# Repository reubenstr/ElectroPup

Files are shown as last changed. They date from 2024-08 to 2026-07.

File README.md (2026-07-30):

# ElectroPup

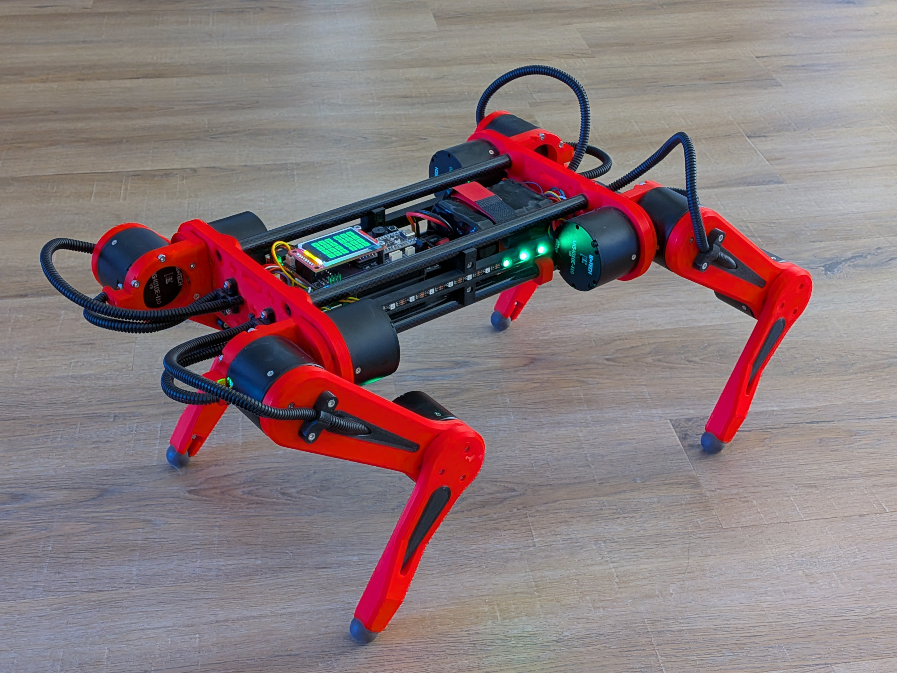
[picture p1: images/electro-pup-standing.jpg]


ElectroPup is a DIY 3D-printed quadruped robot using 'low cost' BLDC motors.

[Video of kinematic poses](https://youtu.be/AJn_wCcWlwo)

[Video of walking, turning, strafing](https://youtu.be/YjTVNw8BXlM)

## Basic Specifications

- RPi 5
- 12x BLDC motors
- Auxiliary board w/LCD display
- 9-axis accelerometer/gyro sensor
- 6s Li-Ion battery, ~72wH
- 4.5kg

ElectroPup's control system is coded in Python. For a ROS2 based quadruped, see my previous project [Zuko](https://github.com/reubenstr/zuko).

# Docs

See the docs directory for a setup guide, bill of materials (BOM), 3D printed parts info, and miscellaneous design notes.

# UI

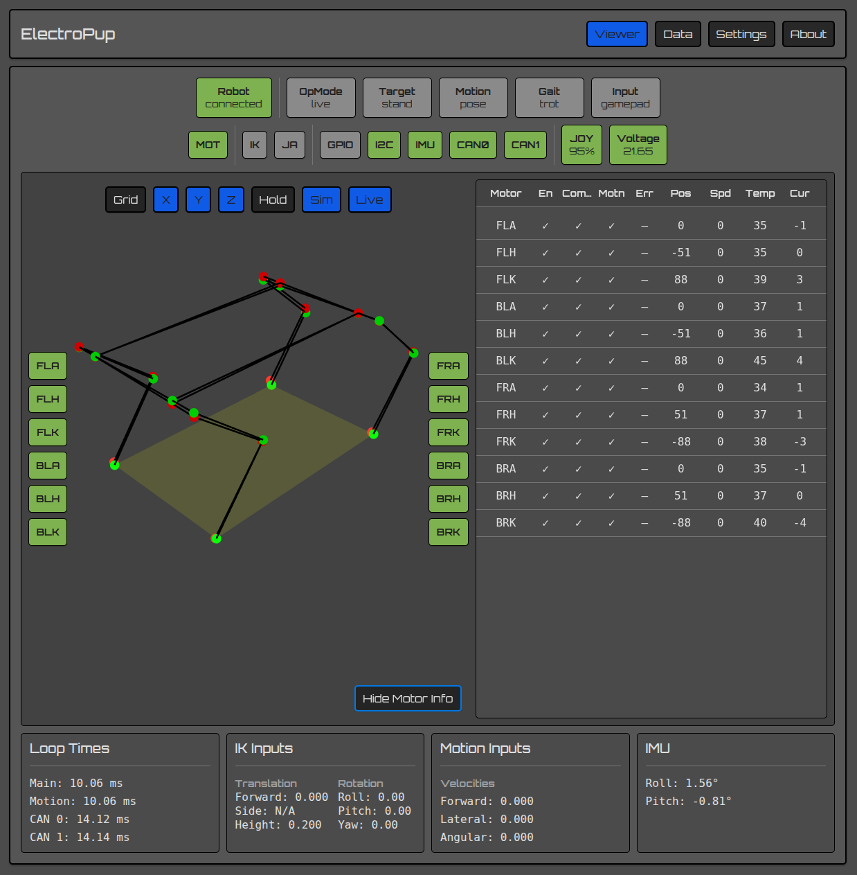
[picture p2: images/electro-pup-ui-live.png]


The UI shows the status of the entire system: quadruped joint positions, subsystem status, motor information, inputs, sensors, loop times, etc. The above image shows the simulated quadruped overlapped with real quadruped (based on motor feedback).

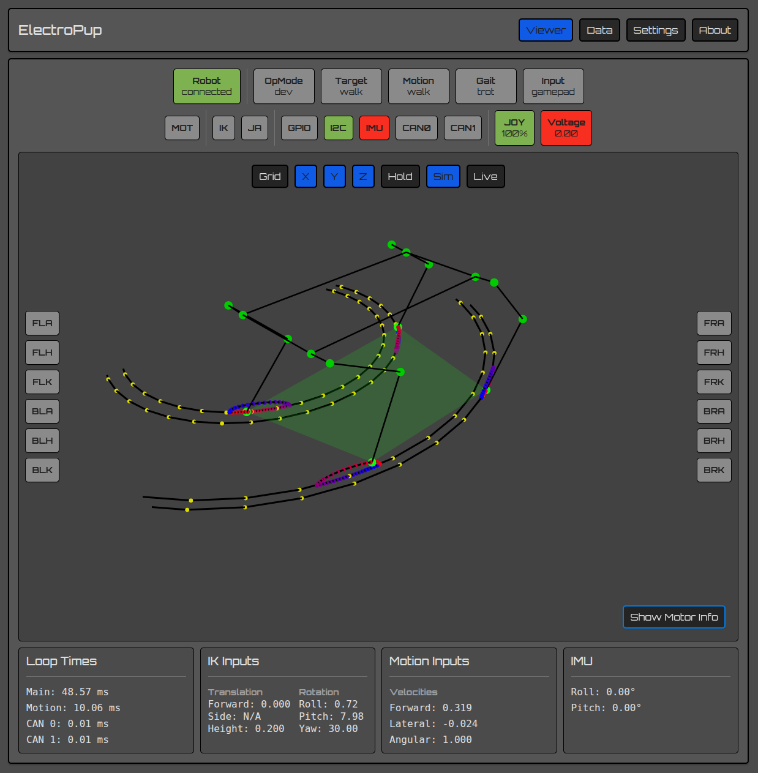
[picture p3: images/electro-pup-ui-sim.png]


The above image shows a virtual circle the feet follow to walk in a circle and the bezier curves used for moving the feet up and down.

The UI is built from the React Native Framework using Expo and runs on web. The app will run on Android without the plot. The entire system runs in dev mode so you can run the simulation and UI from a development PC without physical hardware.

# Kinematics

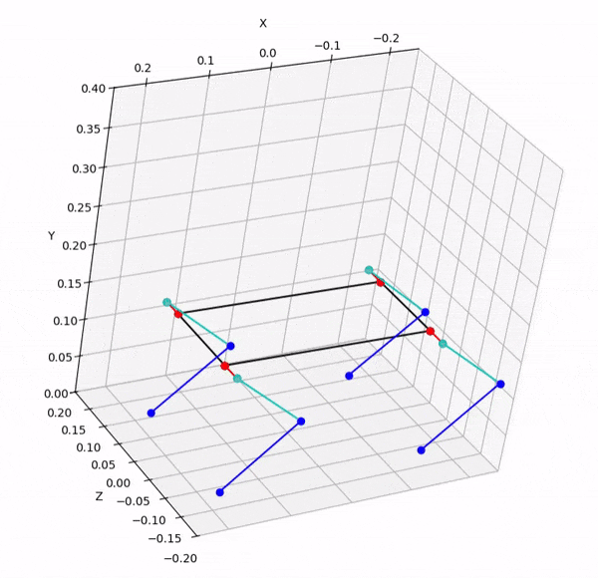
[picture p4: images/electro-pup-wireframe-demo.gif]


Inverse kinematics, leg position, and gamepad inputs are verified using the UI.

### Trajectories

Bezier curves, sin arcs, and curvature projection are used to generate trajectories. The plots below are examples of control points configurations. 

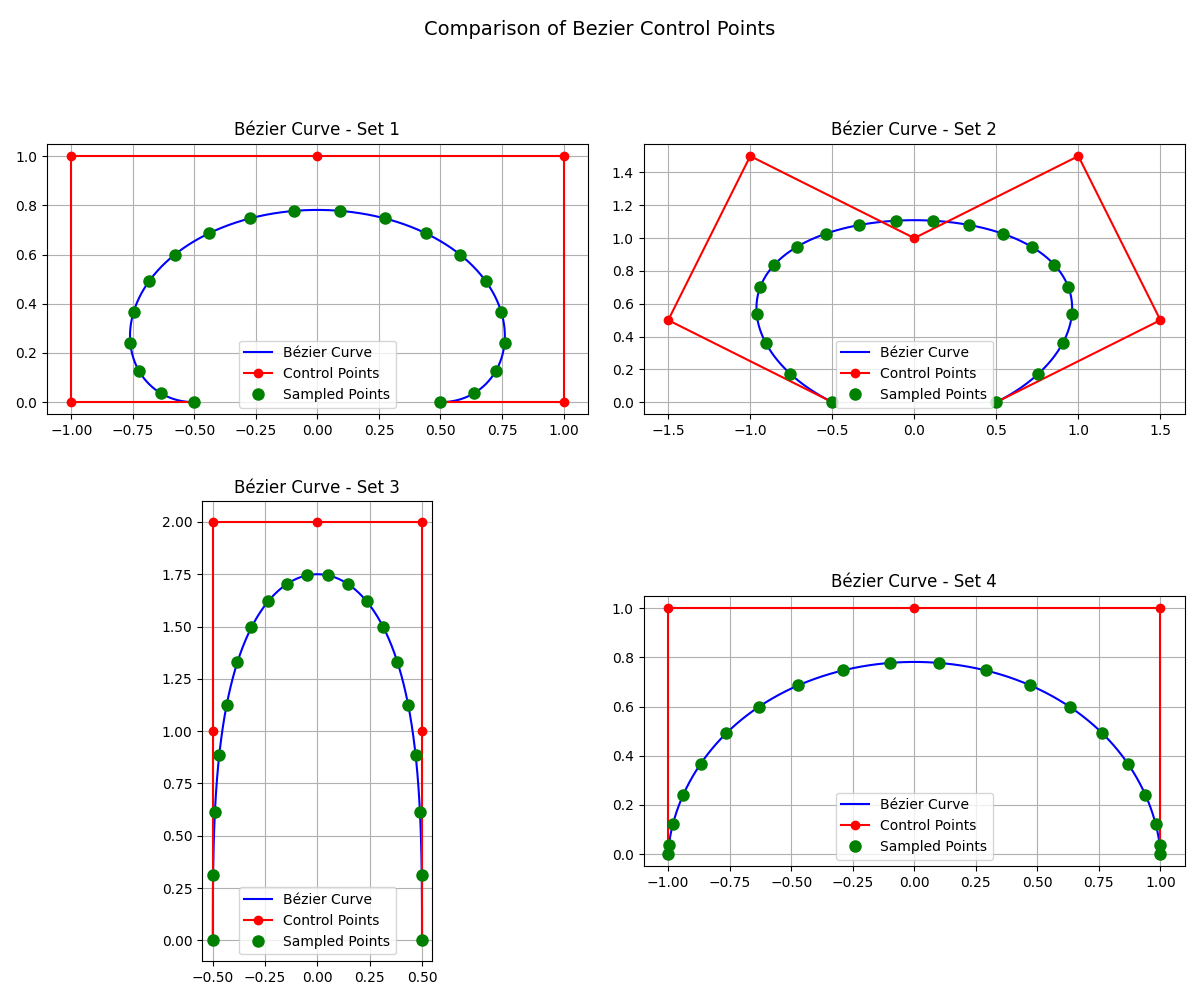
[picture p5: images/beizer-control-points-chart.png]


The output of `./src/plot/bezier_curve_plot.py`

Rotation is achieved by projecting a linear trajectory onto a curve. The plots are of example projection calculations.

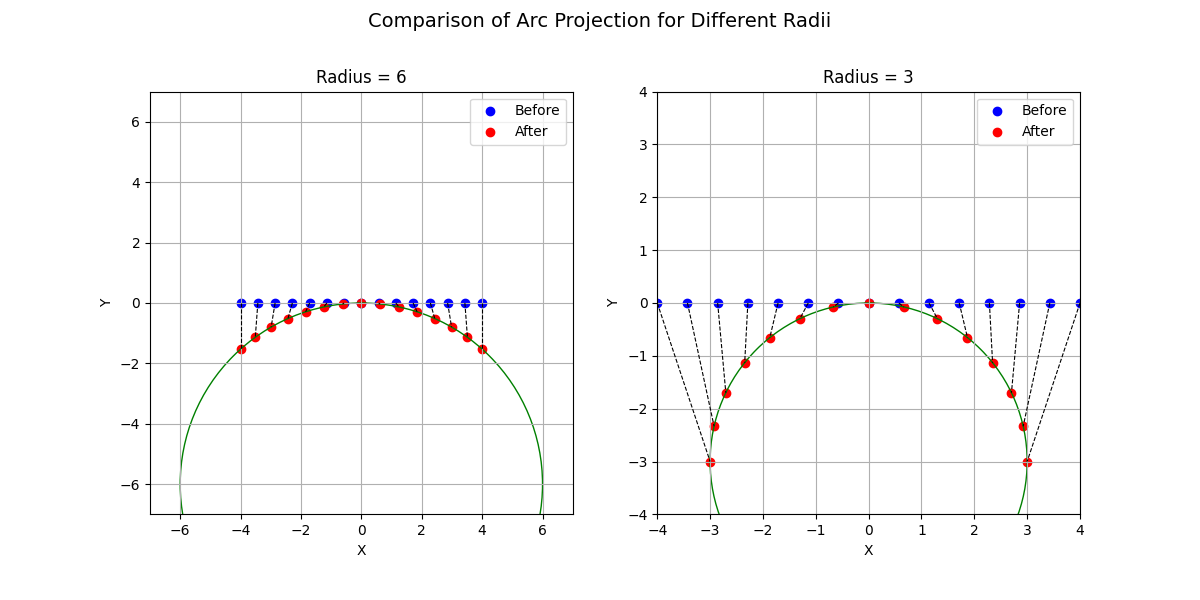
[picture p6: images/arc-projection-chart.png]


The output of `./src/plot/projection_plot.py`

# Simulation

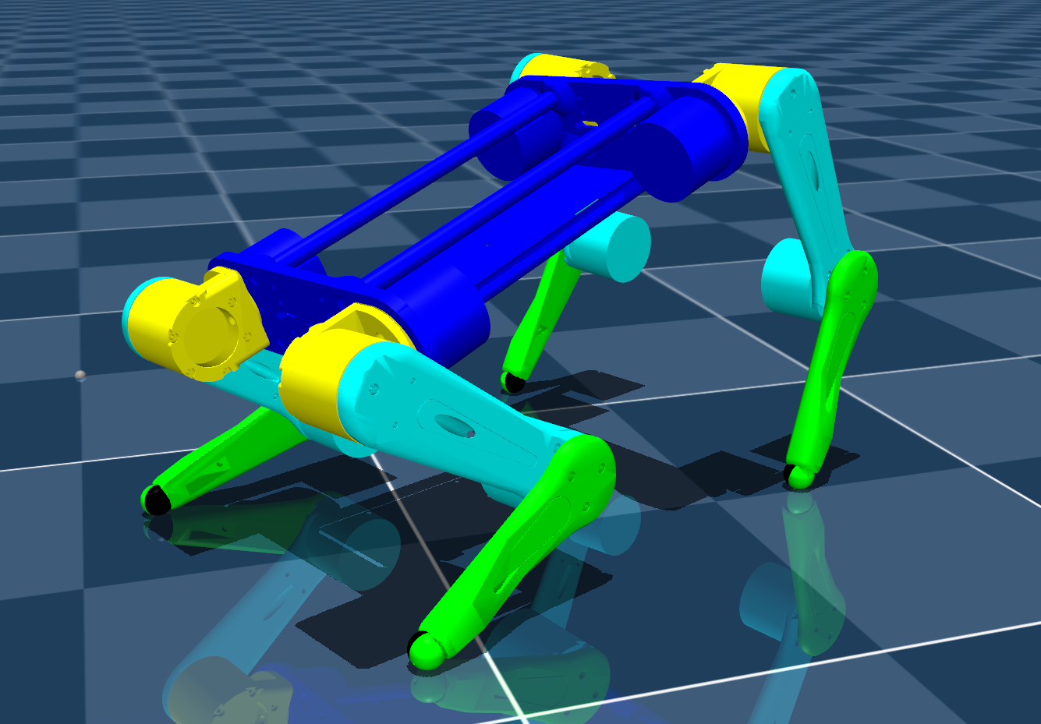
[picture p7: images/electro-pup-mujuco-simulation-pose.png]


Simulation is performed in [MuJoCo](https://mujoco.org/) and can be started by running `./src/sim.sh`. Currently, input controlls are only provided by the gamepad. The `ElectroPup.xml` currently does not have approximate masses or inertial so the simulated quadruped is rather bouncy.

# Electronics

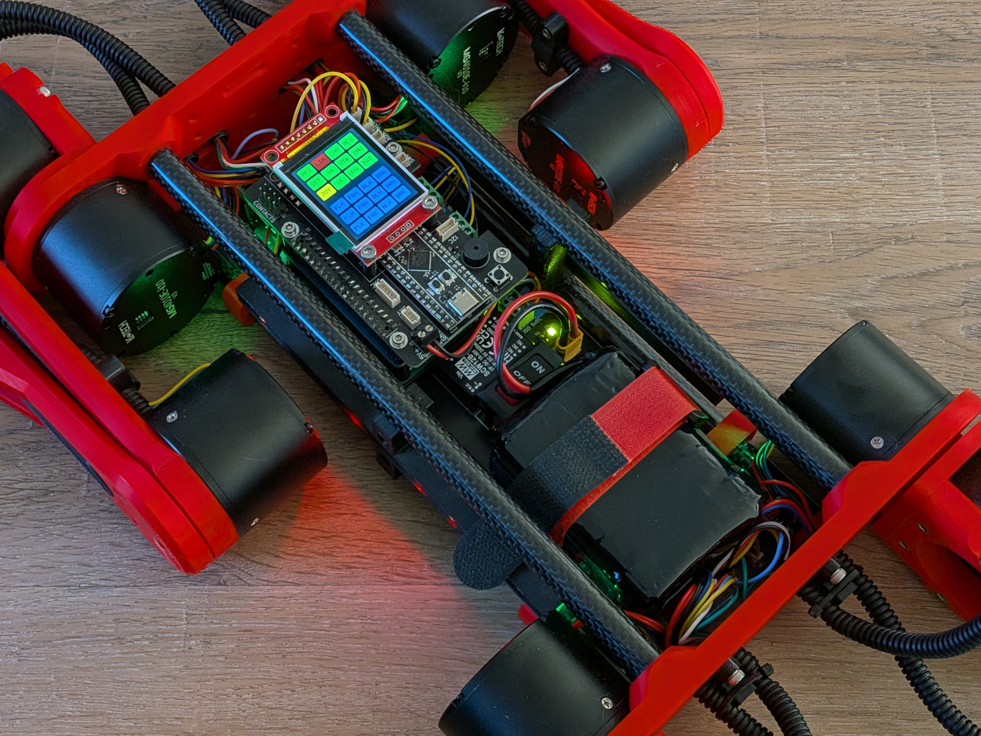
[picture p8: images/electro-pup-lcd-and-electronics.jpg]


## PCBs

PCBs are designed in [KiCad](https://www.kicad.org/) v8 and fabricated by JLCPCB.

### Power Carrier

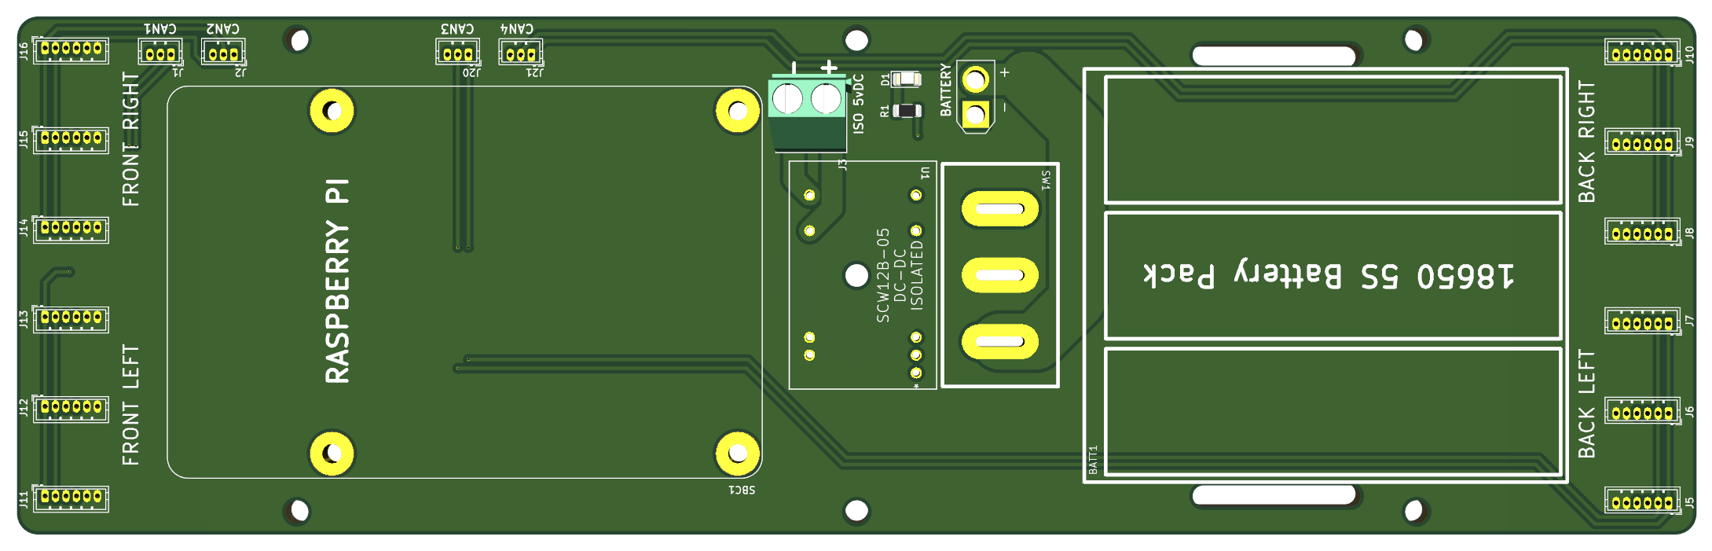
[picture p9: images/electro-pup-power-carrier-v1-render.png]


The Power Carrier PCB provides a main on/off power switch and distributes power to the motor headers. The Power Carrier creates four CAN bus networks one for each leg. Solder jumpers allow merging the front two legs into a single network and the back two legs into another single network.

### Auxiliary Board

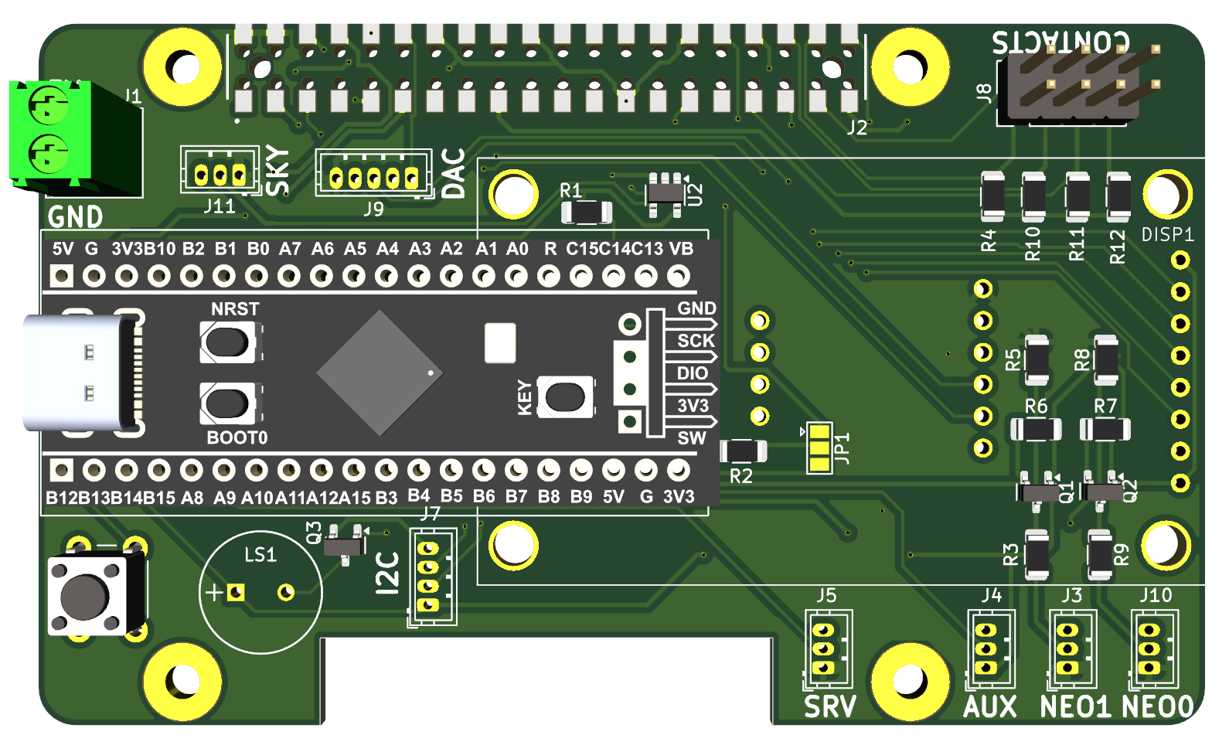
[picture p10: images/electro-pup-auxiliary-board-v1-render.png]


The auxiliary board is optional and not required for the quadruped to operate.

Features:
- Powers RPi via terminal header
- LCD display
- Buzzer (variable pitch)
- NeoPixel strips
- RC Servo channel
- I2C expansion
- Button to control LCD and shutdown Raspberry Pi before power off

Provides direct connection to RPi header for the following breakouts:
- IMU (BNO055 via I2C)
- 4x contact inputs or GPIO
- I2S for sound driver (future barks 🐶)
- SBUS to use RC transmitter if BLE gamepad fails in RF congested areas

# Software Architecture

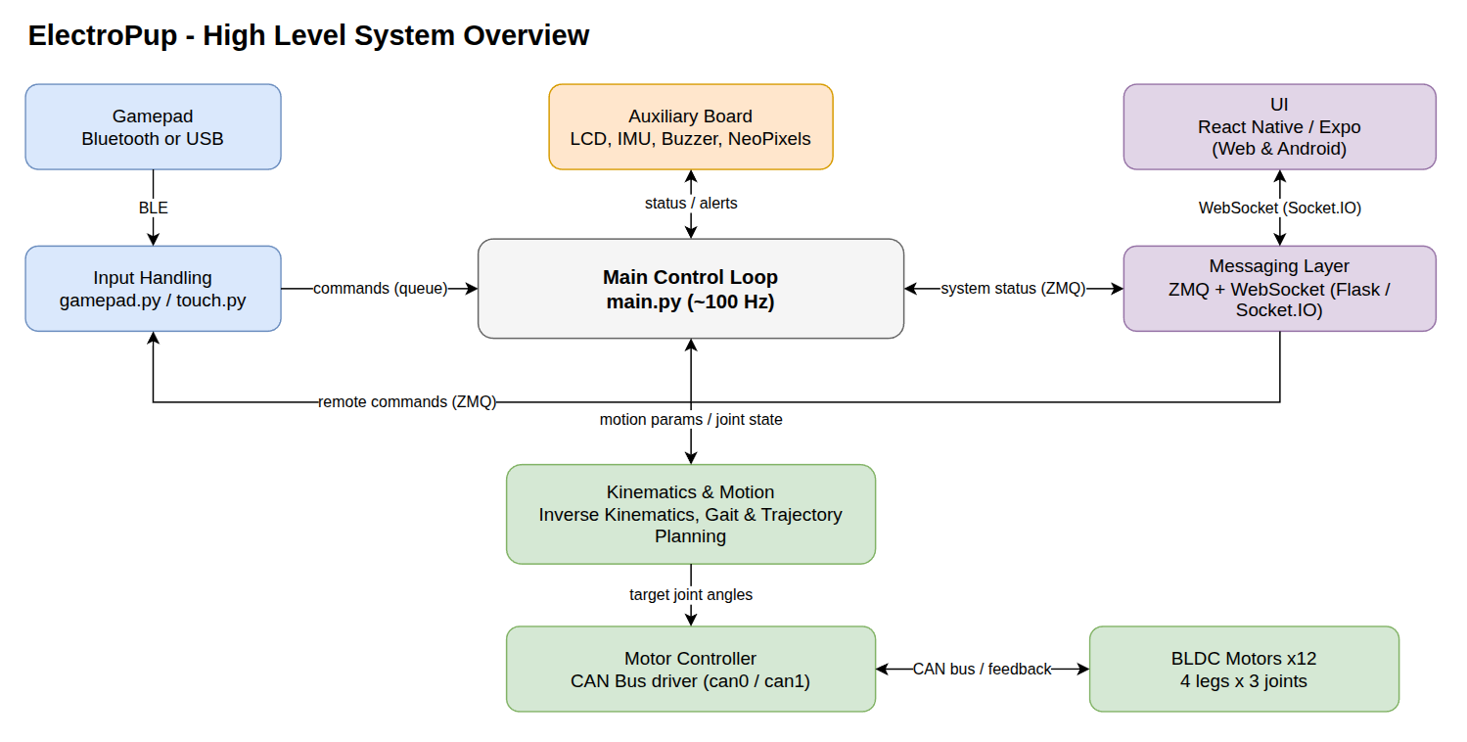
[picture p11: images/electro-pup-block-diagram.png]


Electropup's software architecture was purposely designed to be simple and to bypass the pain points of using ROS2. See my [Zuko]( https://github.com/reubenstr/zuko) robot quadruped for a ROS2 implementation, abiet outdated. A major downside of this single service architecture is needing to sit and stand the quadruped on every software change vs being able to restart individual services quickly without affecting others (i.e. the motors). However, with the simulated quadruped and UI, most development is not performed on a live quadruped.

# Motors

The motors are MG4010E-i10v3 actuators made by LingKong (LKMTECH) and can be purchased from [Aliexpress](https://www.aliexpress.us/item/3256805950420462.html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).

### Specifications
- voltage: 7.4-32V
- communication: CAN 1Mbps
- rated torque: 2.5 N.m
- max torque: 4.5 N.m
- rated current: 3.5 A
- max power: 140 W
- gear ratio: 1:10
- encoders: 18-bit motor, 14-bit reducer
- size: 53mm diameter, 41mm tall
- weight: 238 grams

### MG4010E-i10v3 Pros
- easy to use configuration software over non-proprietary USB to UART hardware
- readable CAN bus communication documentation
- small physical size that works well with the desired frame size of ElectroPup
- non-proprietary power/communications connector (JST-ZH 6-POS)

### MG4010E-i10v3 Cons
- configuration software is Windows only
- closed source firmware
- foreign sourced, complicating the warranty process
- CAN unable to configure all parameters
- UART required to configure error thresholds, motor torque limits (for compliance), etc.
- some motors are more difficult to turn by hand and require slightly more operational current

Future projects will prioritize ODrive compatible drivers.

### Motor Zero Positions

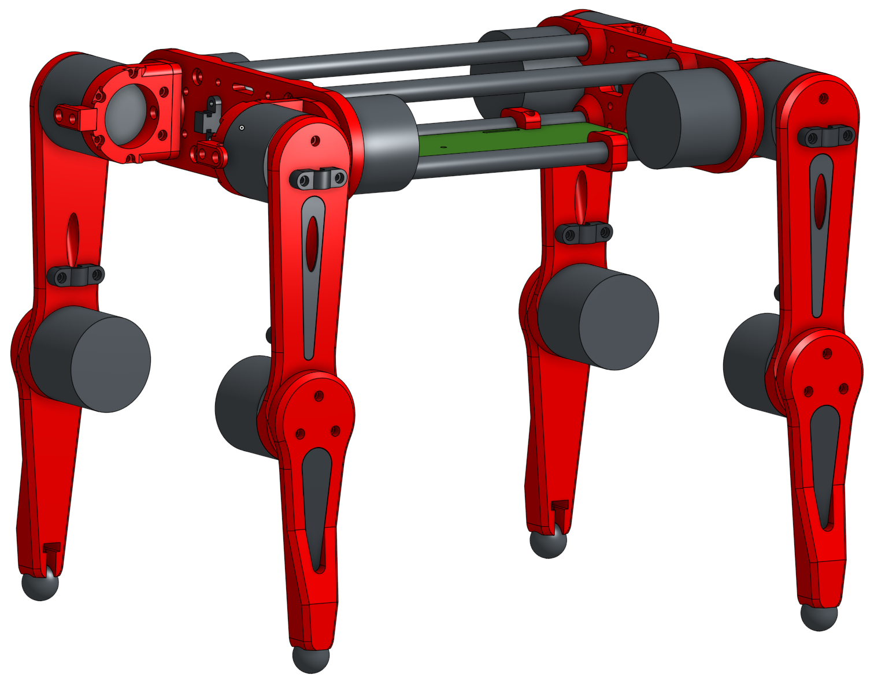
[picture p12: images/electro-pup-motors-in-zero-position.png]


### Motor Tags

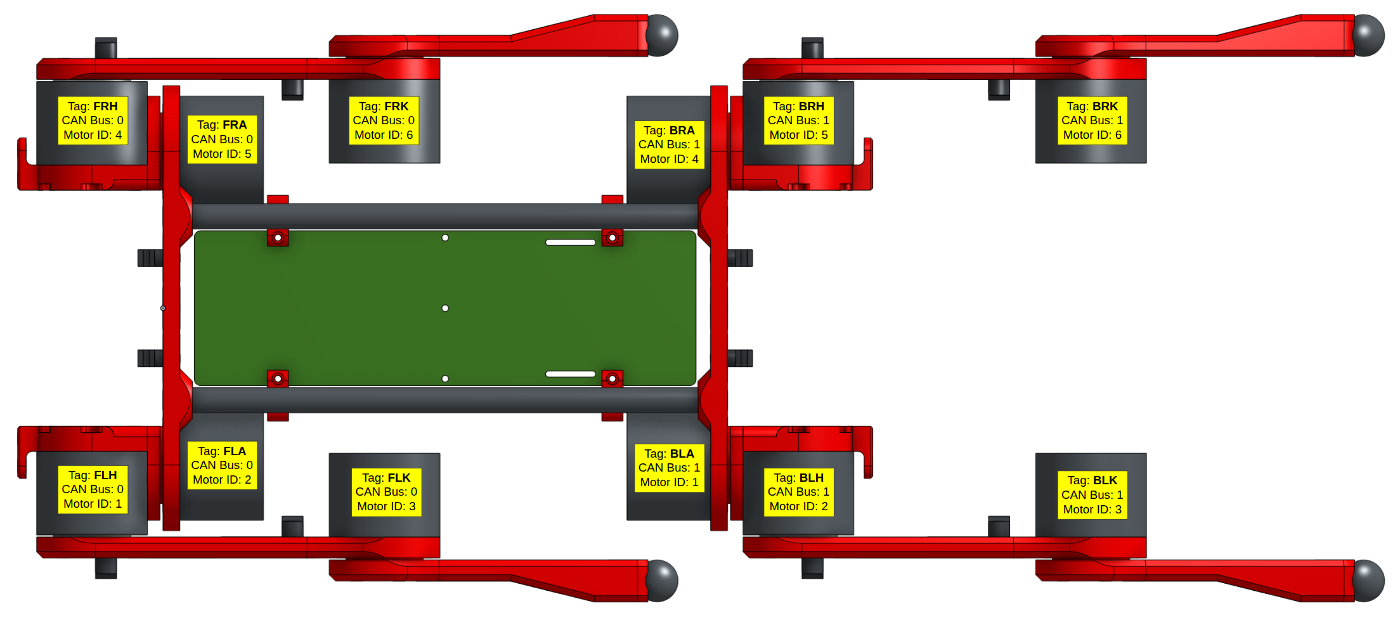
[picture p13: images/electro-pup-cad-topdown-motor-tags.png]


### Motor Calibration

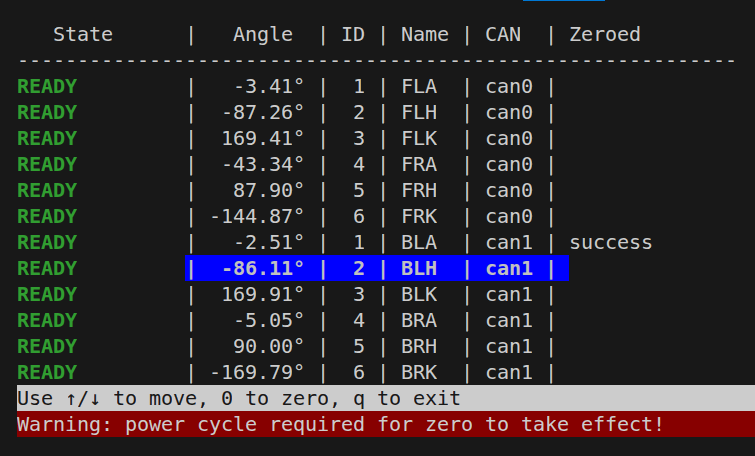
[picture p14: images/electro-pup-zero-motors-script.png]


The zero-motors.py script is a quick way to verify correct motor configuration and to zero the motors.

# CAN Bus

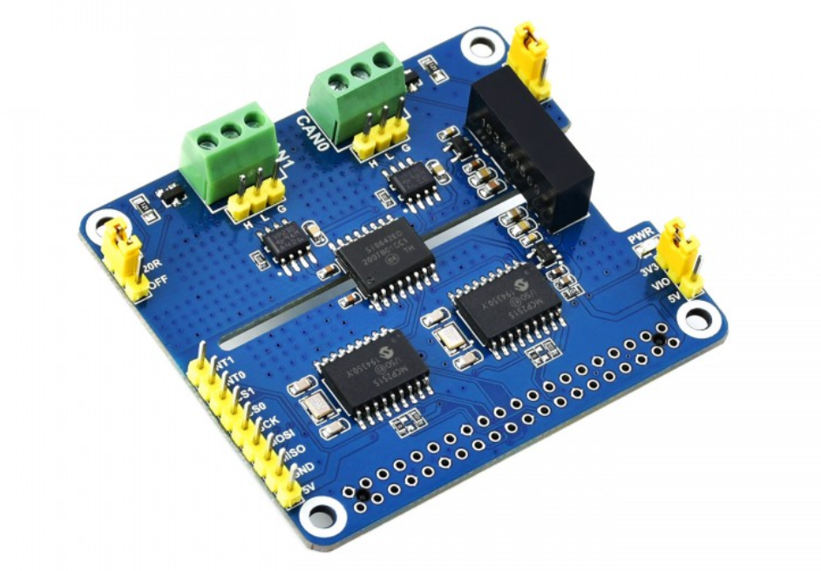
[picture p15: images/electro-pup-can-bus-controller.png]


The CAN bus controller is a [2-Channel Isolated CAN Expansion HAT](https://www.waveshare.com/2-ch-can-hat.htm) from waveshare.

Each CAN controller drives six motors with an average motor update rate of ~70 Hz. This includes fetching encoder position, setting target angle/speed, and getting error states.

# Gamepad

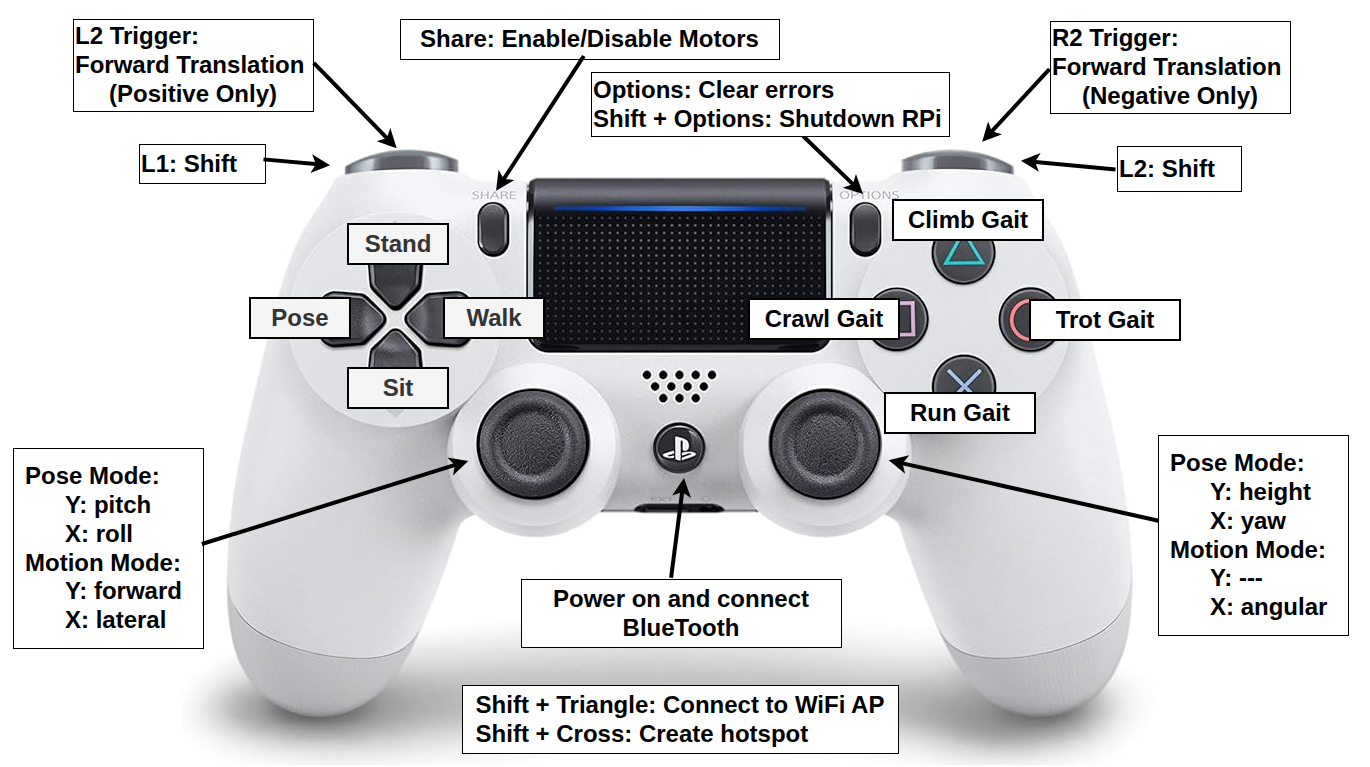
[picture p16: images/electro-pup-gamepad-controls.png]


ElectroPup was coded with a PS4 controller in mind, however xBox, PS5, Logitech gamepads may be used with minor software modifications.

# Environment and IDEs 

There are three hardware/software environments described below.

### PC/Laptop - Plotting, Simulation, and Development

Desktop or laptop computer running Ubuntu Desktop (or your preferred flavor of Linux).

Software: VSCode (with remote SSH and PlatformIO extensions), Drawio, LibreOffice, KiCad, OrcaSlicer, Chrome/Firefox

### Raspberry Pi - Quadruped Hardware Driver

The quadruped compute is a Raspberry Pi 5.

The OS is Raspberry Pi OS Lite (Bookworm 64-bit), which is headless, so all development is performed using remote SSH.

### STM32 - Auxiliary Board

An STM32F401 Black Pill dev kit operates the auxiliary board to display the motor and system status on a LCD display and interface with other peripherals such as the buzzer. 

Uses VSCode with PlatformIO on the PC/Laptop for development.

# Parts

The 3D printed parts are printed using Polymaker PolyMax Tough PLA selected for strength and ease of printing. See these excellent blog posts for more information: [cnckitchen](https://www.cnckitchen.com/blog/the-difference-of-pla-and-pla-tested-feat-polymaker) and [edemargerie](https://www.instructables.com/Comparing-Impact-Resistance-of-21-Filaments-for-3D/).

| Color | Estimated Print Time | Estimated Filament |
| --- | --- | --- |
| main (red) | 25.23 hours | 742 grams |
| accent (black) | 3.58 hours | 92 grams |

### CAD

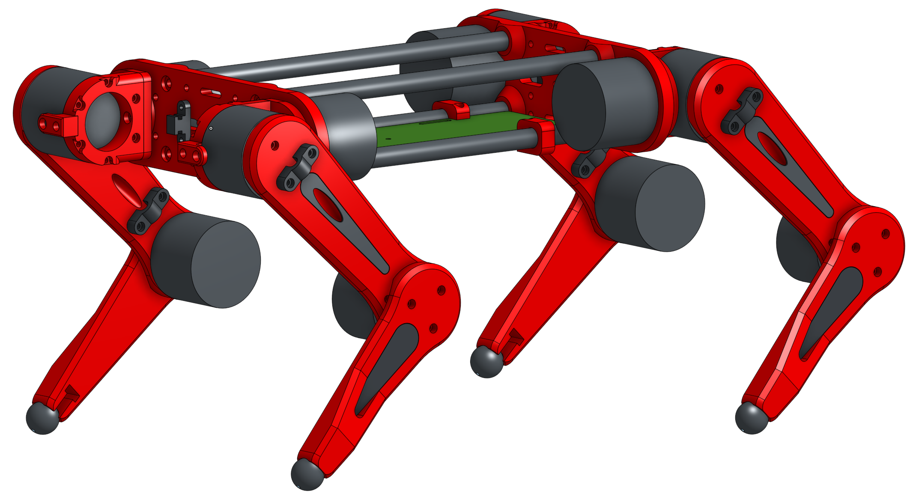
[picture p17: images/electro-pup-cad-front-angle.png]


Parts are modeled using [OnShape](https://www.onshape.com/en/) which provides free web-based full access for non-commercial use. The links below should have export permissions to allow copying the workspace.

- [Assembly](https://cad.onshape.com/documents/b02341d4ebb7f3e9dd488186)
- [Legs](https://cad.onshape.com/documents/6da583196278caf8e90b3122)
- [Body](https://cad.onshape.com/documents/280c24f1b6bdbe8246159786)
- [Hips](https://cad.onshape.com/documents/428031d0c98bf15dcc9f5c8c)
- [Tools](https://cad.onshape.com/documents/3677b35bffbfedb5a3fd2b26)
- [Parts](https://cad.onshape.com/documents/6d4d4e21394ee725ee8ddb38)
- [PCB](https://cad.onshape.com/documents/c8a855826c37bd92b89d9f0e)
- [Neopixels](https://cad.onshape.com/documents/567292ac55c75b2efa25b7d5)

# Battery Pack 

The battery is a custom 6S1P Li-Ion using 18650s with a load balancing BMS. The 18650's are Sanyo branded and rated at 3250mAH each providing an estimated 72Wh.

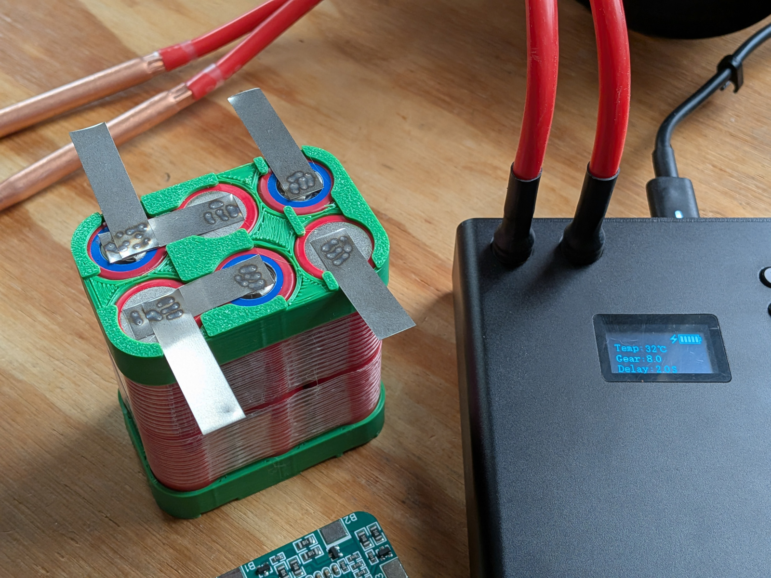
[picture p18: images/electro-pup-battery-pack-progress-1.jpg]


The above image is showing work in progress. The [insulation rings](https://imrbatteries.com/products/18650-terminal-insulators-fish-paper-20pcs-green-round-rings) were forgotten during fabrication and really should be mandatory for any battery build. 

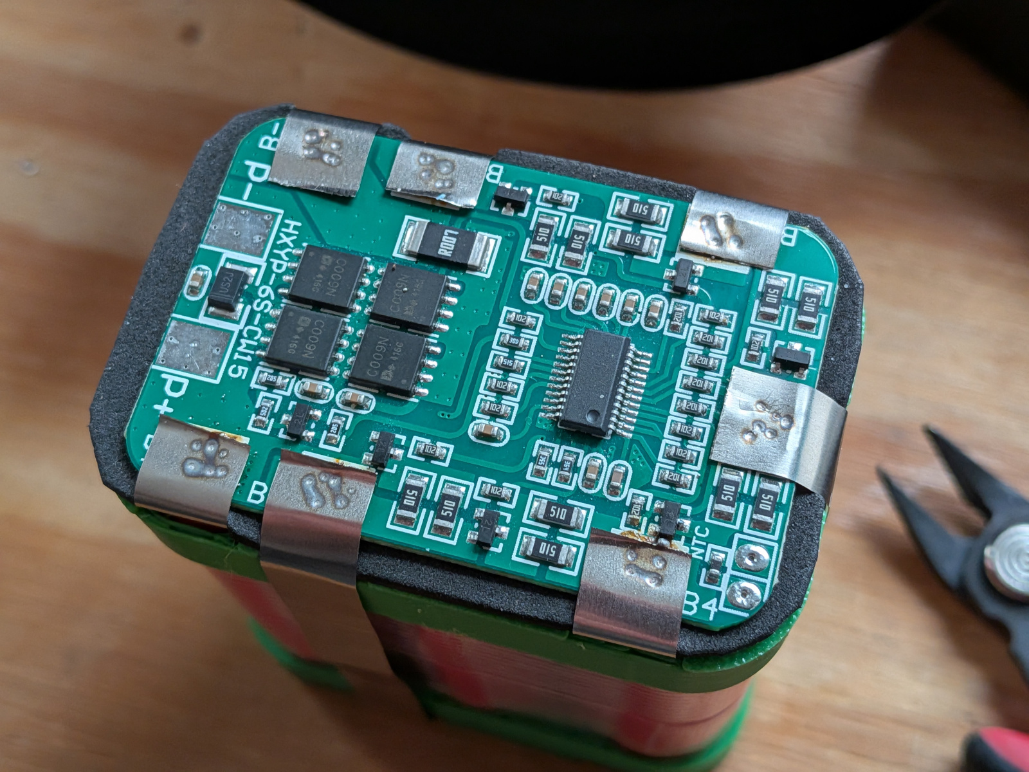
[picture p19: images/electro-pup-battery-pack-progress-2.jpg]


The BMS is a HXYP-6S-CW15.

# Future Improvements  

This is a general improvement list for future updates or revisions. 

- add upside down control (the frame supports walking even after flipped)
- apply IMU for smoother gaits
- add center of mass calculations for smoother gaits
- swap battery and RPi positions for better center of mass
- swap foot lag bolt from SAE to metric
- add curvature to lower leg
- add speaker for barks
- add a tail
- add voltage/current sensor (such as an INA228)
- remove STM32 from aux board and use RPI directly for buzzer, LCD, etc.
- create a [MPC](https://en.wikipedia.org/wiki/Model_predictive_control) controller

# Thoughts

- Due to a lower power consumption than estimated, a larger frame and longer legs can be created. A larger frame would support moving the knee motor to the hip area allowing the lower leg to be belt driven. The reduction of mass of the knee will increase center of mass stability and create smoother gaits.
- Future Auxiliary board revisions will remove the STM32 and either drive the LCD directly from the RPi or remove it completely. The extra complexity outweighs the LCD's usefulness, especially when the GUI provides significantly more data.
- Future power carrier PCB revisions will include a voltage/current sensor such as a INA228 and a fuse.
- The carbon rods twist during the run gait which can be reduced by extending the rods through the hip plates and adding face / butt plates. 
- Future revisions will prioritize adding contact sensors that will allow for better terrain handling and future AI training.
- A full architecture refactor splitting major components into services would have the advantages of individual unit testing and keeping the quadruped standing during development.

# Questions

For any questions please post a new [issue](https://github.com/reubenstr/ElectroPup/issues) on the repo's GitHub page.

# Credits

Inverse kinematics and leg points for plotting were sourced from mike4192: [https://github.com/mike4192/](https://github.com/mike4192/).

Using carbon fiber tube as frame supports inspired from [Open Dog 3](https://www.youtube.com/watch?v=ts2l_Em7fpI&list=PLpwJoq86vov8uTgd8_WNgBHFpDYemO-OJ&index=3) by James Bruton.

There are many excellent open source quadruped robot projects at various sizes, costs, and complexity. Below are projects and code examples worth checking out.

- https://github.com/mit-biomimetics/Cheetah-Software
- https://github.com/mike4192/spotMicro
- https://github.com/mike4192/spot_micro_kinematics_python
- https://spotmicroai.readthedocs.io/en/latest/
- https://github.com/adham-elarabawy/open-quadruped
- https://www.youtube.com/jamesbruton
- https://github.com/chvmp/champ
- https://grabcad.com/library/diy-quadruped-robot-1
- https://github.com/Jerome-Graves/yertle
- https://www.youtube.com/@Jorgefer88
- https://www.youtube.com/watch?v=oYnsCE2H6ss
- https://github.com/JackDemeter/quadruped-robot
- https://github.com/reubenstr/zuko

# AI Disclosure

Project concept, aesthetic, engineering design, and original code base were conceived and executed by the author.

Portions of this codebase were reviewed, revised, and written with the assistance of Claude Code (Anthropic).

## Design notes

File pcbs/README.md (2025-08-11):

# PCBs

PCBs are designed in [KiCad](https://www.kicad.org/) (v8)

Custom libraries used for these projects may be found on my github repo: [https://github.com/reubenstr/kicad-libraries](https://github.com/reubenstr/kicad-libraries)

See the README.md in each project for next revision error fixes.

## Auxiliary Board

This board uses a STM32 co-processor to add the following functionality to the system:

- LCD display for error indication and status such as battery levels
- 1x buzzer
- 2x Neopixel strips
- 1x RC servo
- 1x button

This board also provides the following Raspberry Pi connection breakouts:
- BNO055 IMU
- SBUS FrSKY RC receiver input
- I2S header
- 4x contact switches (or aux GPIO)

## Power Carrier

This board provides the following functionality:
- Power distribution for the actuators
- CAN bus networks for the actuators
- Isolated DC-DC for the Raspberry Pi
- Main power On/Off switch
- Battery holder and power connection

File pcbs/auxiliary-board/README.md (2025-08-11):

# TODO / Fixes

- Add version number to silkscreen
- Change terminal footprint to match the now used terminal: WM7877-ND 
- Add a switch for WiFi AP/Client switching
- LCD holes are not aligned and are off slightly
- Change 40 pin header from SMD to through-hold
- Consider adding a second tactile button

# General Thoughts

- Removing the Black Pill in favor of using a STM32 directly on the board will save space and allow the addition of more breakouts such as buttons.

- Removing the LCD PCB and directly connecting a LCD to the board will reduce the height of the board that will decrease the chance of screen damage when the quadruped rolls over.

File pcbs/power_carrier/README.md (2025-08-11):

# TODO / Fixes

- Add voltage/current sensor such as a INA228
- Add revision number to silkscreen
- Optional: Add motor tags (ex, FLA, FLH, FLK) to silkscreen
- Move 5vDC terminal away from RPi as this blocks the power switch if a RPi 5 is used.
- Some of the PCB may be removed to save weight, perhaps under the battery.

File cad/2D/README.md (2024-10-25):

# 2D CAD

electropup.dwg contains the 2D CAD drawing of the quadruped.

2D CAD was used as a quick method to layout major components and determine part sizes prior to generating parts in 3D CAD.

The 2D CAD drawing has not been updated to reflect the final 3D version.

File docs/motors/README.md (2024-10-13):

# Actuators

Model: MG4010E-i10v3

Purchased from the Chinese company LingKong (Shanghai Lingkong Technology Co., Ltd.) also branded as LKMTECH 

LingKong products: http://en.lkmotor.cn/Product.aspx

Aliexpress: https://www.aliexpress.us/item/3256805950420462.html

As of 09/2024 LingKong has not released the CAD model of the MG4010E-i10v3

# Misc.

There is ESP32 project to communicate using the common MCP2515 SPI CAN controller: https://github.com/project-sternbergia/lkm_m5/tree/main

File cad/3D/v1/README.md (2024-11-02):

# 3D CAD : V1

Version 1 parts as STLs for quick reference.

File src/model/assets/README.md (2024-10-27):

# Assets

For model infomation and links see the cad/3D/README.md doc.

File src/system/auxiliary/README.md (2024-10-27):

# Auxiliary

Auxiliary is a set of optional functionality that sends system status data
to the auxiliary Raspberry Pi hat with a display, neopixels, and misc hardware.

## Heartbeat

The auxilary board expects a heartbeat signal (on GPIO17) from the Raspberry Pi as an indication
if the Raspberry Pi has booted and is operational.

Execute the install_heartbeat.sh on the Raspberry Pi to install and start the heartbeat service.

Check the service status:
>sudo systemctl status heartbeat.service 

Stop the service:
>sudo systemctl stop heartbeat.service 

Start the service:

>sudo systemctl start heartbeat.service

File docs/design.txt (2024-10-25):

###############################################################################
# Design
###############################################################################

Notes taken during the design process.

###############################################################################
# MG4010E Motors
###############################################################################

Measured motor bolt MAX depths:
Front frame: M2.5 x 8.5mm, recommended max: 8mm
Front motor wheel: M3 x 6mm, recommended max: 5.5mm
Front motor wheel pin: M3 x 3mm, recommended max 2.5mm

###############################################################################
# MIT Mini Cheetah
###############################################################################

The MIT Mini Cheetah was source of inspiration and it's dimensions are recorded as a sanity check to help ElectroPup's frame stays within common proportions.

Units: mm
Frame width (side to side): 194
Frame length (front hip plate to back hip plate): 304
Frame thickness (top to bottom): 94

Hip width (actuator center ot actuator center): 236.5
Hip length (actuator center to actuator center): 392

Hip center motor to upper leg (actuator center to actuator center): est. 82

Foot width (ball to ball): 256
Foot length (ball to ball): 392

Upper leg length: 212.4
Lower leg length: 205

###############################################################################
# Other Motors and Interfaces
###############################################################################

https://github.com/open-dynamic-robot-initiative/blmc_drivers?tab=readme-ov-file
https://open-dynamic-robot-initiative.github.io/robot_interfaces/doc/real_time.html

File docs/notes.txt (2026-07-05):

###############################################################################
# Notes
###############################################################################

Notes taken during design, testing, and assembly.

###############################################################################
# Power
###############################################################################

Fully loaded:
    Abduction at zero degrees, legs at 45 degrees
    Suspended (motors disabled): 1.08A @ 20vDC = 21.6 watts
    Standing (motors enabled): 1.79A @ 20vDC = 33.8 watts

Battery:
    6x 18650 in series, 24v nominal
    At 3300mAh per cell: 12.21Wh x 6 == 73.26Wh

###############################################################################
# Body
###############################################################################

Carbon fiber tube: 12mm OD, 10mm ID, 254mm length
In retrospect the frame probably could of been shorted by 4mm to require 250mm 
tubes as this is a more common length. However, only a few listings (aliexpress only)
have been found at the required dimensions at 250mm length.

To use a 250mm length either the Power Carrier PCB will need to be shortend (by 2 to 4mm),
or a slot can be added to the hip plate to allow the PCB to slip in the needed ~1mm per end.

The carbon fiber rods have PLA inserts on both ends which in turn holds a M5 brass insert.
The PLA inserts attach to the ends of the rod using superglue. 
About five minutes after the superglue is applied the threaded inserts can be applied to the PLA insert. 
(Do not wait for the glue to cure.)
Superglue will ooze out from the PLA insert which will allow the PLA insert to better form to the rod.

When attaching the carbon fiber rods to the hip plate, add the PCB clips to the lower rods first, then attach the rods loosely.
Place the body on a flat surface and while holding the hip plates down cycle through each rod tightening the rod a little bit each cycle.

###############################################################################
# Motor and Leg Hardware
###############################################################################

Hip:
    motor front: 6x M2.5x12mm
    motor wheel: 2x M3x14mm
    motor wheel: 1x M3x25mm

Upper Leg:    
    motor back: 6x M3x18mm
    motor wheel: 1x M3x12mm
    motor wheel: 2x M3x20mm  
    motor wheel pin: 3x M3 x 8mm
    wireclip upper side: M3x8mm (M3x10mm OK)
    wireclip lower side: M3x8mm (M3x10mm OK)

Lower Leg:    
    motor front: 6  
    motor wheel: 3x M3x20mm
    motor wheel pin: 3x M3 x 8mm

###############################################################################
# Motors
###############################################################################

After the all the motors are physically attached each motor will need to be configured 
prior to connecting the final wiring.
(See docs for motor ID and parameter setup)

###############################################################################
# Motor Cables 
###############################################################################

Motor cables use 6 position JST-ZH headers on each end and have the following lengths (housing to housing):
4x each: 60mm, 235mm, 465mm

Motor cables are contained in 7mm OD splitloom tubing and have the following lengths:
4x each: 155mm, 465mm

The short length cables are made from the cable that was provided with the motor.
The longer length cable is made from 26AWG silicon wire.

The crimps on the second housing for the two longer cables should be placed into the housing until after the cable is routed through the wire clip and leg.

###############################################################################
# CAN Bus Communication
###############################################################################

Timing sample of processing 6 motors on a single CAN bus:
    Performs: 
        self._worker_set_all_targets()                                
        self._worker_get_all_angles()                                        
        self._worker_get_all_status()                
        self._worker_check_all_angle_limits() 
    Capture (milliseconds):
        [Motors] processing time: 12.37
        [Motors] processing time: 16.80
        [Motors] processing time: 12.23
        [Motors] processing time: 17.36
        [Motors] processing time: 12.58
        [Motors] processing time: 12.00
        [Motors] processing time: 16.46
        [Motors] processing time: 11.73
        [Motors] processing time: 15.99
        [Motors] processing time: 12.25
        [Motors] processing time: 16.09
        [Motors] processing time: 12.59
        [Motors] processing time: 15.77
        [Motors] processing time: 12.09
        [Motors] processing time: 16.13
        [Motors] processing time: 12.58
        [Motors] processing time: 15.24
        [Motors] processing time: 12.61
        [Motors] processing time: 16.75

###############################################################################
# Tools
###############################################################################

Make gifs:
https://ezgif.com/

Make LCD splashscreen:
https://github.com/riuson/lcd-image-converter

Better top:
sudo apt install htop

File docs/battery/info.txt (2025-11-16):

6x 18650 in series forr 24v nominal.
At 3300mAh per cell: 12.21Wh x 6 == 73.26Wh

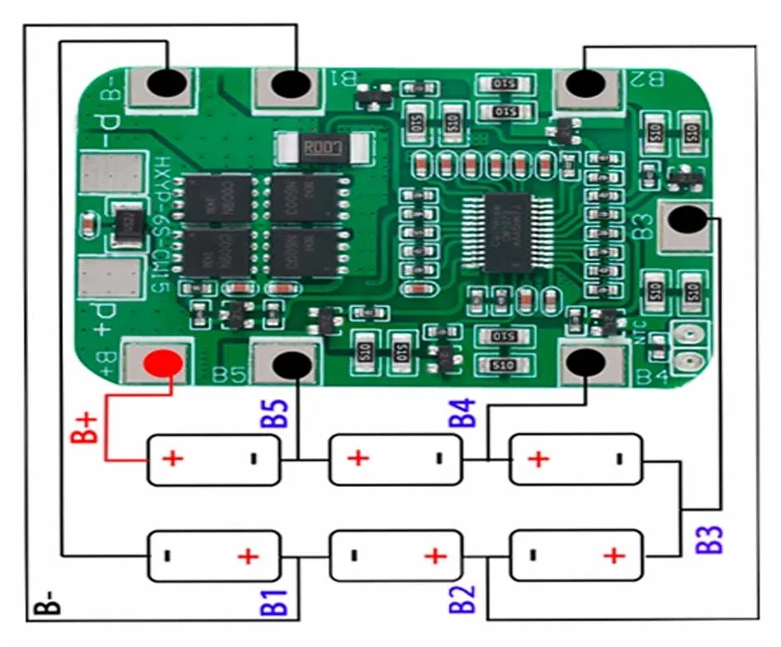
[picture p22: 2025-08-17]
docs/battery/6s-18650-lipo-general-connections.png

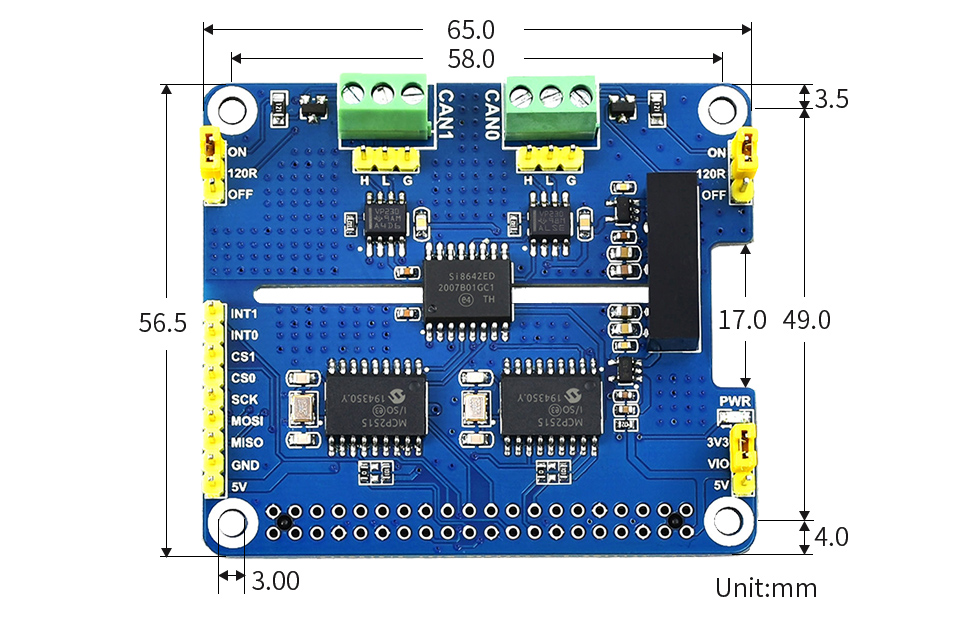
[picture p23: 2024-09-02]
docs/can/2-CH-CAN-HAT-17_960.jpg

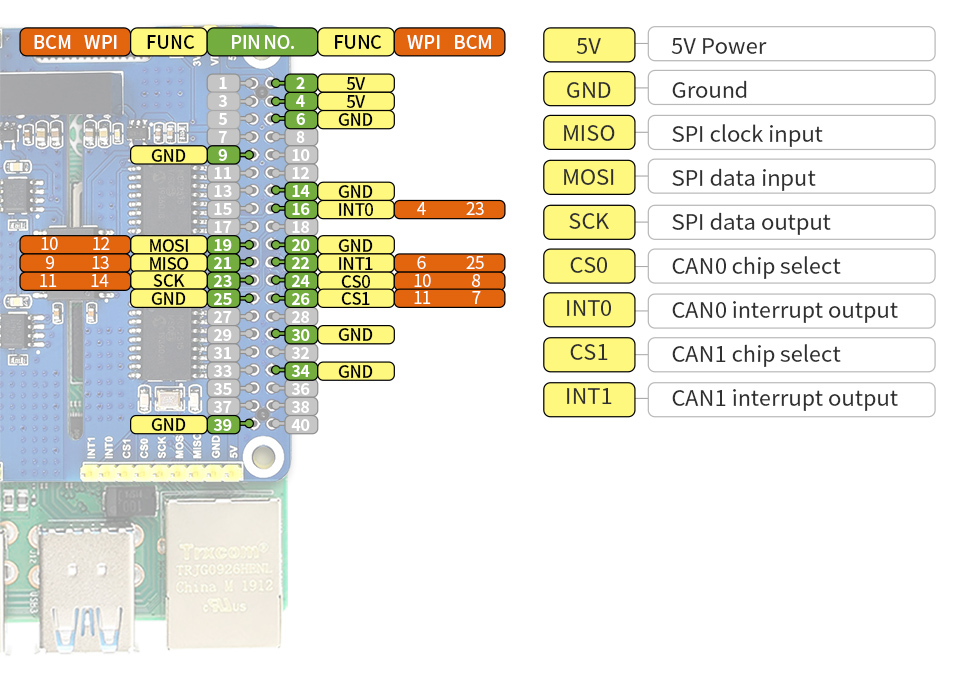
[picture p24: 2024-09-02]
docs/can/2-CH-CAN-HAT-15_960.jpg

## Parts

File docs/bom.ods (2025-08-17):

Bill of Materials
Costs are for estimate purposes only and may not include bulk orders, taxes, tariffs, or shipping.
You will always need more parts than the final quantity due to losses and failures.
Links are provided as reference only, carefully review before making purchases.
Hardware | Qty | Est. Cost | SubTotal | Link 1 | Link 2 | Notes
M2.5x12mm socket head bolt | 24 | 0.05 | 1.2 | mcmaster (https://www.mcmaster.com/91292A115/)
M2.5x14mm socket head bolt | 24 | 0.05 | 1.2 | mcmaster (https://www.mcmaster.com/91292A017/)
M2.5x40mm socket head bolt | 4 | 0.261 | 1.044 | mcmaster (https://www.mcmaster.com/91292A837/)
M3x8mm socket head bolt | 32 | 0.05 | 1.6 | mcmaster (https://www.mcmaster.com/91292A112/)
M3x12mm socket head bolt | 4 | 0.05 | 0.2 | mcmaster (https://www.mcmaster.com/91292A112/)
M3x14mm socket head bolt | 8 | 0.05 | 0.4 | mcmaster (https://www.mcmaster.com/91292A027/)
M3x16mm socket head bolt | 4 | 0.05 | 0.2 | mcmaster (https://www.mcmaster.com/91292A027/)
M3x18mm socket head bolt | 24 | 0.05 | 1.2 | mcmaster (https://www.mcmaster.com/91292A029/)
M3x20mm socket head bolt | 20 | 0.05 | 1 | mcmaster (https://www.mcmaster.com/91292A123/)
M3x25mm socket head bolt | 4 | 0.05 | 0.2 | mcmaster (https://www.mcmaster.com/91292A027/)
M5x16mm low-profile bolt | 8 | 0.25 | 2 | amazon (https://www.amazon.com/M5-Countersunk-Socket-Screws-Furniture/dp/B0CKW3791R) | aliexpress (https://www.aliexpress.us/item/3256806833766304.html)
M2.5 nylon lock nut | 4 | 0.1 | 0.4 |  | aliexpress (https://www.aliexpress.us/item/2251832612458814.html)
M3x4mm 4.5mm diameter brass insert | 28 | 0.05 | 1.4 |  | aliexpress (https://www.aliexpress.us/item/3256805034317562.html)
M5x10mm 7mm diameter Brass Insert | 8 | 0.25 | 2 |  | aliexpress (https://www.aliexpress.us/item/3256803396040989.html)
M3x8mm Pin (non-threaded) | 36 | 0.12 | 4.32 |  | aliexpress (https://www.aliexpress.us/item/3256807033465642.html)
1/4-in x 1-in Zinc-Plated Hex-Head Lag Screws | 4 | 0.23 | 0.92 |  | lowes (https://www.lowes.com/pd/Hillman-1-4-in-x-1-in-Silver-Zinc-Plated-Hex-Head-Interior-Lag-Screw/3036823) | Used to attach foot beads to lower leg. M6 25mm is metric equivalent, lower leg model will need tweaked
Frame
Polymaker PolyMax Tough PLA Red - 1.75mm – 750g | 2 | 29.99 | 59.98 | amazon (https://www.amazon.com/dp/B09KLFPZFJ)
20mm silicon bead | 4 | 1.38 | 5.52 | aliexpress (https://www.aliexpress.us/item/3256805271172037.html) |  | Feet
Carbon fiber tube 12mm ID x 10mm ID x 254mm | 4 | 5 | 20 | amazon (https://www.amazon.com/dp/B0D546MSBL) |  | If purchasing 250mm lengths, the hip plate needs a slight modification for fit
Electromechanical
MG4010E-i10v3 actuator (CAN version) | 12 | 134 | 1608 | aliexpress (https://www.aliexpress.us/item/3256805950420462.html) |  | Purchase as needed to avoid expensive tariffs! (sets of three)
Electronics
PCB: Power Carrier | 1 | 15 | 15 |  |  | Split cost after shipping from JLCPCB
PCB: Auxiliary Board | 1 | 15 | 15 |  |  | Split cost after shipping from JLCPCB
Raspberry Pi 4 | 1 | 55 | 55 | digikey (https://www.digikey.com/en/products/detail/raspberry-pi/SC0194-9/10258781)
Micro SD card | 1 | 10 | 10
Waveshare 2-Ch CAN Bus HAT | 1 | 25.99 | 25.99 | amazon (http://18650batterystore/) | waveshare (https://www.waveshare.com/2-ch-can-hat.htm)
40 pin header | 1
40 pin header | 1
Gamepad – PS4 Controller | 1 | 30 | 30 |  |  | xBox, PS5, or F710 controllers will work with minor software changes
WS2812b strip – 5mm wide, black PCB, 5V | 1 | 4.96 | 4.96 |  | aliexpress (https://www.aliexpress.us/item/3256806803085615.html) | Non-water proof for easier soldering. Link is for white PCB.
26AWG Silicon wire assorted colors | 1 | 18 | 18 | amazon (http://BNO055/) |  | A assorted box with 6 colors is by far more than enough wiring
Split loom tubing, 7mm OD | 1 | 1.99 | 1.99 |  | aliexpress (https://www.aliexpress.us/item/3256803623149093.html)
STM32 Black Pill dev kit | 1 | 3.07 | 3.07 | amazon (https://www.aliexpress.us/item/3256801269871873.html) | aliexpress (https://www.aliexpress.us/item/3256801269871873.html)
LCD display 128x160 1.8” (HiLetGo) | 1 | 2.45 | 2.45 | amazon (https://www.amazon.com/DIYmalls-Display-Interface-ST7735S-Mega2560/dp/B0BFDQDGSQ) | aliexpress (https://www.aliexpress.us/item/3256806134563059.html)
BNO055 IMU Adafruit Layout | 1 | 29.95 | 29.95 | adafruit (https://www.adafruit.com/product/4646)
2.54mm header low-profile | 1 |  |  |  |  | For LCD. TBD
SWITCH ROCKER SPST 20A 125V | 1 | 1.27 | 1.27 | digikey (https://www.digikey.com/en/products/detail/zf-electronics/CRE22F4DBBNE/446067)
DC DC CONVERTER 5V 12W | 1 | 16.91 | 16.91 | digikey (https://www.digikey.com/en/products/detail/mean-well-usa-inc/SCW12B-05/7706439)
BUZZER MAGNETIC 3V 9MM TH | 1 | 2.04 | 2.04 | https://www.digikey.com/en/products/detail/mallory-sonalert-products-inc/PB-09N23P-03Q/3196328
SWITCH TACTILE SPST-NO 0.05A 24V | 1 | 0.16 | 0.16 | https://www.digikey.com/en/products/detail/te-connectivity-alcoswitch-switches/1825910-6/1632536
IC INVERTER 1CH 1-INP SOT23-5 | 1 | 0.83 | 0.83 | https://www.digikey.com/en/products/detail/texas-instruments/SN74LVC1G14DBVT/1592006
TRANS NPN 40V 0.6A SOT23-3 | 2 | 0.1 | 0.2 | https://www.digikey.com/en/products/detail/onsemi/MMBT2222ALT1G/919593
RES 10K OHM 1% 1/8W 0805 | 12 | 0.02 | 0.24 | https://www.digikey.com/en/products/detail/vishay-dale/CRCW080510K0FKEAC/7928398
RES 1.2K OHM 1% 1/4W 1206 | 1 | 0.1 | 0.1 | https://www.digikey.com/en/products/detail/yageo/RC1206FR-071K2L/728411
RES 500 OHM 1% 1/4W 1206 | 2
LED GREEN CLEAR 1206 SMD | 1 | 0.22 | 0.22 | https://www.digikey.com/en/products/detail/w%C3%BCrth-elektronik/150120GS75000/4489936
TERM BLK 2POS SIDE ENT 3.5MM PCB | 2 | 1.27 | 2.54 | https://www.digikey.com/en/products/detail/molex/0393570002/946543
3-pos JST-ZH header | 5 | 0.161 | 0.805 | https://www.digikey.com/en/products/detail/jst-sales-america-inc/B3B-ZR/926565
4-pos JST-ZH header | 5 | 0.192 | 0.96 | https://www.digikey.com/en/products/detail/jst-sales-america-inc/B4B-ZR/926566
5-pos JST-ZH header | 1 | 0.223 | 0.223 | https://www.digikey.com/en/products/detail/jst-sales-america-inc/B5B-ZR/926567
6-pos JST-ZH header | 12 | 0.195 | 2.34 | https://www.digikey.com/en/products/detail/jst-sales-america-inc/B6B-ZR/926568
3-pos JST-ZH housing | 4 | 0.06 | 0.24 | https://www.digikey.com/en/products/detail/jst-sales-america-inc/ZHR-3/608602
4-pos JST-ZH housing | 1 | 0.075 | 0.075 | digikey (https://www.digikey.com/en/products/detail/jst-sales-america-inc/ZHR-4/608643)
5-pos JST-ZH housing | 1 | 0.054 | 0.054 | digikey (https://www.digikey.com/en/products/detail/jst-sales-america-inc/ZHR-6/527361)
6-pos JST-ZH housing | 8 | 0.131 | 1.048 | digikey (https://www.digikey.com/en/products/detail/jst-sales-america-inc/ZHR-6/527361)
CONN SOCKET 26-28AWG CRIMP TIN | 250 | 0.01888 | 4.72 | digikey (https://www.digikey.com/en/products/detail/jst-sales-america-inc/SZH-002T-P0-5/527363)
Amass XT30 – male | 1 | 1 | 0.5 | aliexpress (https://www.aliexpress.us/item/3256805962254012.html) | amazon (https://www.amazon.com/10Pairs-Upgrade-Connector-Female-Battery/dp/B08P5HVMYT) | Typically bought as a male female set
Battery Pack
18650 Batteries – Sanyo | 8 | 5.99 | 47.92 | 18650batterystore (http://amazon/)
6s LiPo BMS | 1 | 2.16 | 2.16 |  | aliexpress (https://www.aliexpress.us/item/3256806014066125.html)
Nickel strip | 1 | 9.99 | 9.99 | amazon (https://www.amazon.com/dp/B07P4F1QNR) |  | Only buy pure nickel strips, plated does not have enough current capacity
Heat shrink wrapper |  |  |  |  | aliexpress (https://www.aliexpress.us/item/3256806551556294.html)
Wire |  |  |  |  |  | See miscellaneous section
Amass XT30 – female | 1 | 1 | 0.5 | aliexpress (https://www.aliexpress.us/item/3256805962254012.html) | amazon (https://www.amazon.com/10Pairs-Upgrade-Connector-Female-Battery/dp/B08P5HVMYT) | Typically bought as a male female set
Miscellaneous
Zip ties, 2mm width | 1 | 2 | 2
USB-C cable | 1 | 0 | 0 | Junk drawer
18AWG silicon wire – RED | 1 | 2.05 | 2.05 |  | aliexpress (https://www.aliexpress.us/item/3256805878407264.html) | To power robot while suspended during calibration and development
18AWG silicon wire – BLACK | 1 | 2.11 | 2.11 |  | aliexpress (https://www.aliexpress.us/item/3256805878407264.html) | To power robot while suspended during calibration and development
Consumables
super glue
solder
rope/twine |  |  |  |  |  | Suspending robot during configuration
 |  | Total | 2026.399
Tools
3D Printer
Soldering station
Heatset insert tool |  |  |  |  |  | Optional for more stable insert installation
Hex driver set
JST crimper
Wire stripper
Wire cutter
Angled needle nose pliers
Measuring tape (metric)
Benchtop power supply
Nickel welder |  |  |  |  |  | Making battery packs

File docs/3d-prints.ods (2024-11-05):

ElectroPup V1 Frame
Estimated filament and print times (fairly accurate in my experience)
Prusa MK4S
5 top and bottom layers
5 perimeter walls
40% rectilinear infill
Part | Grams | Minutes | QTY | SubTotal Grams | SubTotal Minutes
Main Color
carbon-fiber-tube-insert | 1 | 7 | 8 | 8 | 56
hip-motor-bracket-base | 18 | 40 | 4 | 72 | 160
hip-motor-bracket-riser | 17 | 43 | 4 | 68 | 172
hip-plate | 75 | 166 | 2 | 150 | 332
hip-wire-clip | 3 | 9 | 4 | 12 | 36
lower-leg | 46 | 75 | 4 | 184 | 300
pcb-to-tube-clip | 4 | 11 | 4 | 16 | 44
upper-leg | 58 | 108 | 4 | 232 | 432
Accent Color
lower-leg-accent | 2 | 3 | 4 | 8 | 12
upper-leg-accent | 2 | 3 | 4 | 8 | 12
splitloom-clip | 2 | 8 | 4 | 8 | 32
splitloom-to-leg-clip | 2 | 9 | 8 | 16 | 72
neopixel-strip-holder | 15 | 31 | 2 | 30 | 62
neopixel-strip-holder-clip | 3 | 11 | 2 | 6 | 22
spacer-15mm | 4 | 1 | 1 | 4 | 1
spacer-11mm | 8 | 1 | 1 | 8 | 1
spacer-2.5mm | 4 | 1 | 1 | 4 | 1
Total Main Color |  |  |  | 742 | 1532 | Minutes
 |  |  |  |  | 25.53 | Hours
Total Accent Color |  |  |  | 92 | 215 | Minutes
 |  |  |  |  | 3.58 | Hours

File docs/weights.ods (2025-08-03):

 | Measured Weights
 | (Estimations marked)
 | Item | Qty | Weight (grams) | Subtotal | Notes
 | Motor | 12 | 238 | 2856
 | Upper leg | 4 | 49.8 | 199.2 | 3D printed part
 | Lower leg | 4 | 40 | 160 | 3D printed part
 | Hip motor bracket (combined) | 4 | 30.6 | 122.4 | 3D printed part, assembly
 | Hip plate | 2 | 62.3 | 124.6 | 3D printed part
 | PCB clip | 4 | 3.4 | 13.6 | 3D printed part
 | Foot – Silicon bead | 4 | 5.6 | 22.4
 | CF Rod w/insert | 4 | 17 | 68 | assembly
 | M5x15mm low-profile | 8 | 2.3 | 18.4
 | Foot Lag Bolt | 4 | 6.7 | 26.8
Estimated | Battery Pack | 1 | 300 | 300 | assembly
 | Power Carrier PCB | 1 | 70 | 70 | Populated, no Rpi, no battery
 | Raspberry Pi Stack | 1 | 140 | 140 | Assembly: Rpi, CAN, Aux, and hardware
Estimated | Wires | 1 | 100 | 100
Estimated | Split-loom tubing | 1 | 10
 | Neopixel strip | 2 | 20.6 | 41.2 | assembly
 | Miscellaneous | 1 | 50 | 50
 |  |  | TOTAL (grams) | 4312.6

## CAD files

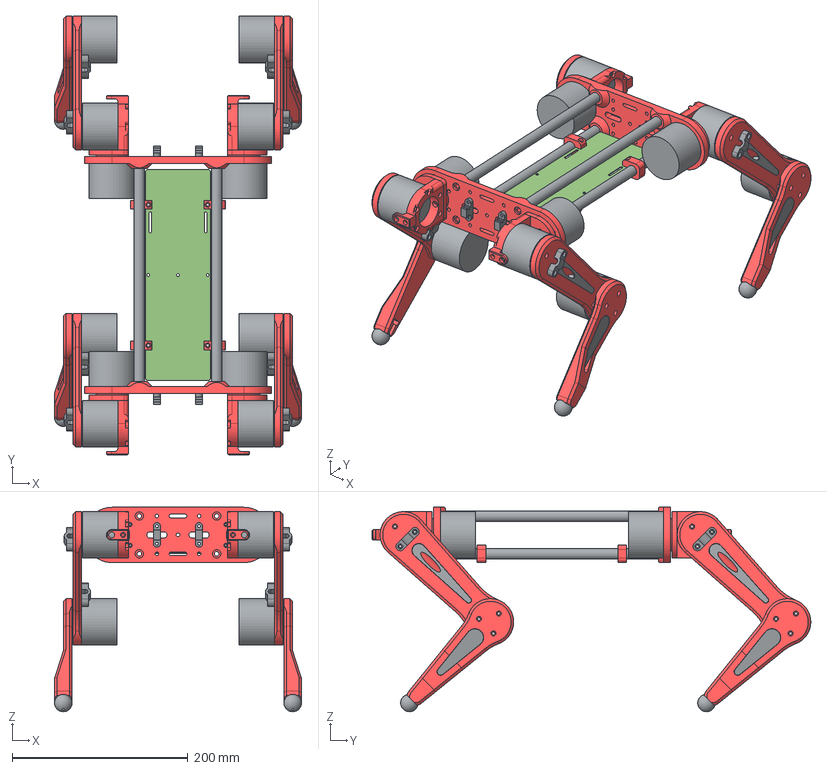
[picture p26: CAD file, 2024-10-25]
cad/3D/v1/assembly-v20.step
281.0 x 499.0 x 232.7 mm
Wire Clamp - Upper Leg - Top x 8
Upper Leg x 4
MG4010E-i10v3 x 12
Accent x 4
Lower Leg - Leg Inteface x 4
Foot - Ball x 4
Leg Accent x 4
Hip Motor Bracket - Base x 4
Hip Motor Bracket - Riser x 4
Hip Wire Clip x 4
Hip Plate x 2
PCB to Tube Clip x 4
Carbon Fiber Tube 12mm OD 10mm ID x 4
Splitloom Clip x 4
PCB Footprint

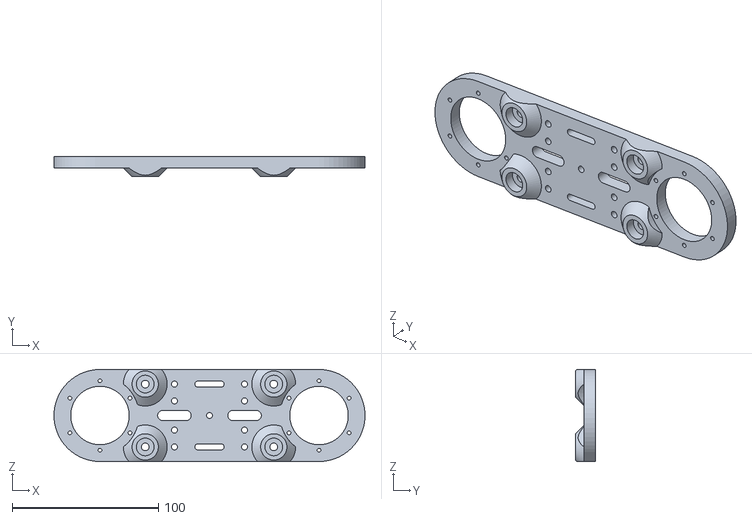
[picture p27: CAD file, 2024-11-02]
cad/3D/v1/hip-plate.stl
212.9 x 14.0 x 63.0

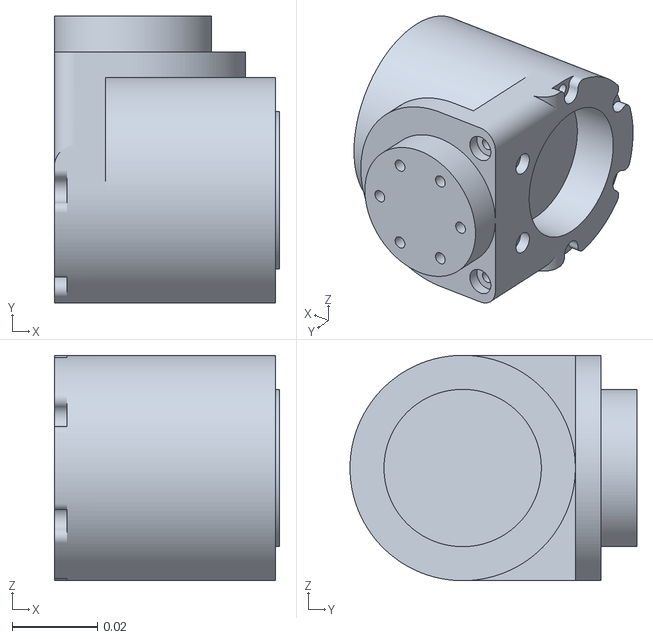
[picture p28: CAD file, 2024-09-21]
src/model/assets/abduction.stl
0.053 x 0.0675 x 0.053

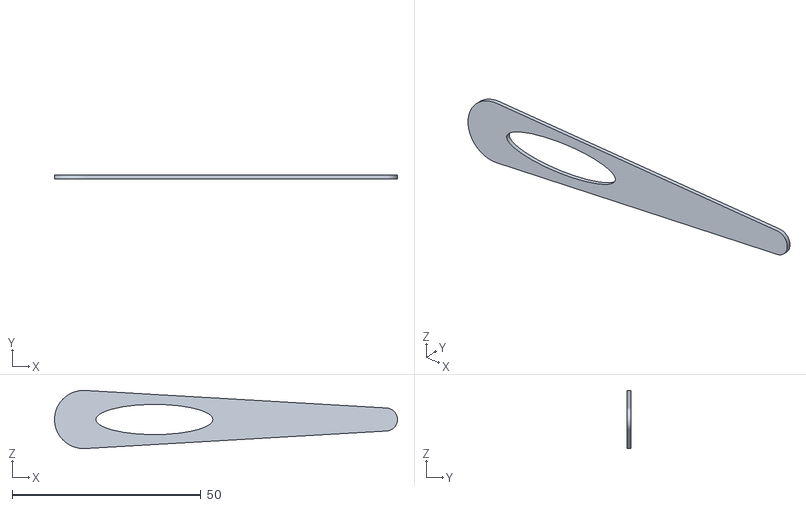
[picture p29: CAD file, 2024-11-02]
cad/3D/v1/upper-leg-accent.stl
90.8 x 1.00 x 15.4

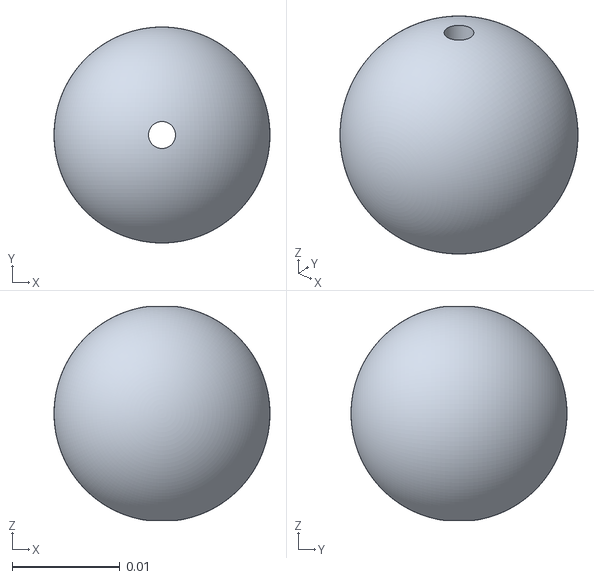
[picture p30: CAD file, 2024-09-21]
src/model/assets/foot.stl
0.02 x 0.02 x 0.0198

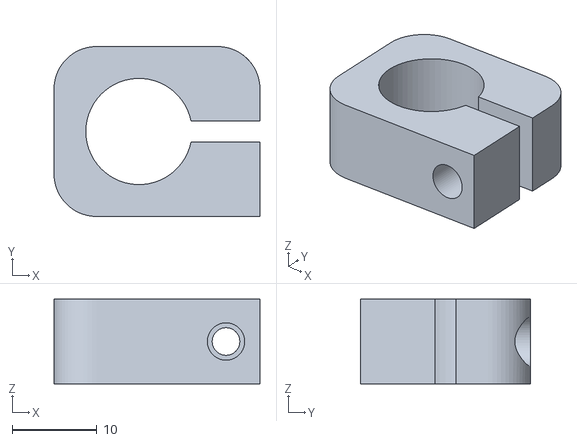
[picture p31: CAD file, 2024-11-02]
cad/3D/v1/pcb-to-tube-clip.stl
24.2 x 20.0 x 10.0

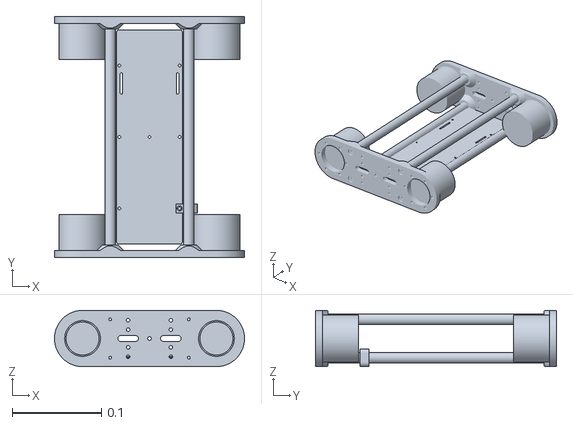
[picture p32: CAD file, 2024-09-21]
src/model/assets/body.stl
0.213 x 0.27 x 0.063

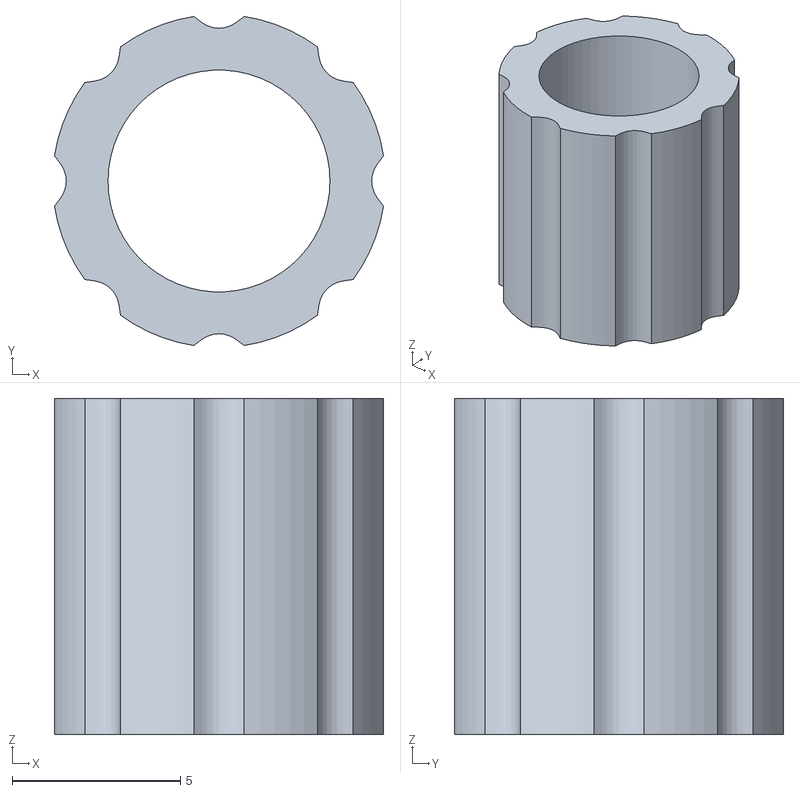
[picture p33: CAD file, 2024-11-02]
cad/3D/v1/carbon-fiber-tube-insert.stl
9.79 x 9.79 x 10.0

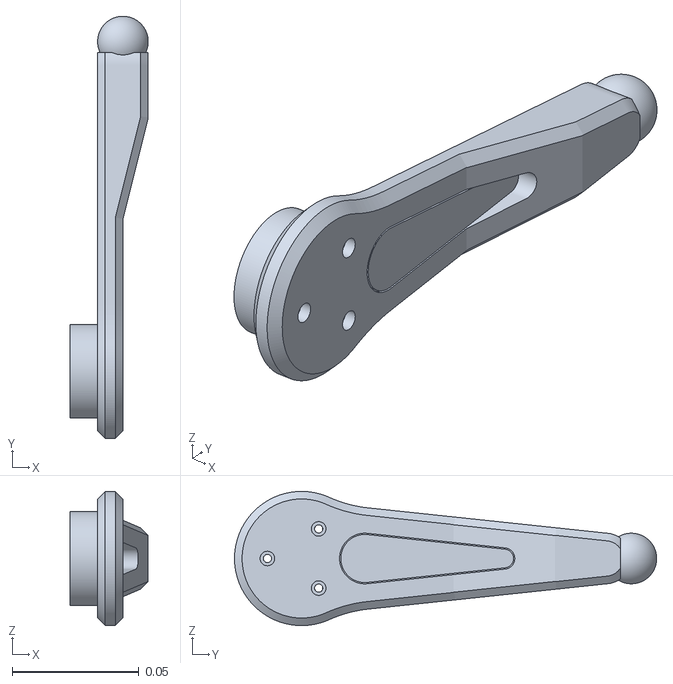
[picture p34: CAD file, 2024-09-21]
src/model/assets/lower-leg.stl
0.031 x 0.167 x 0.053

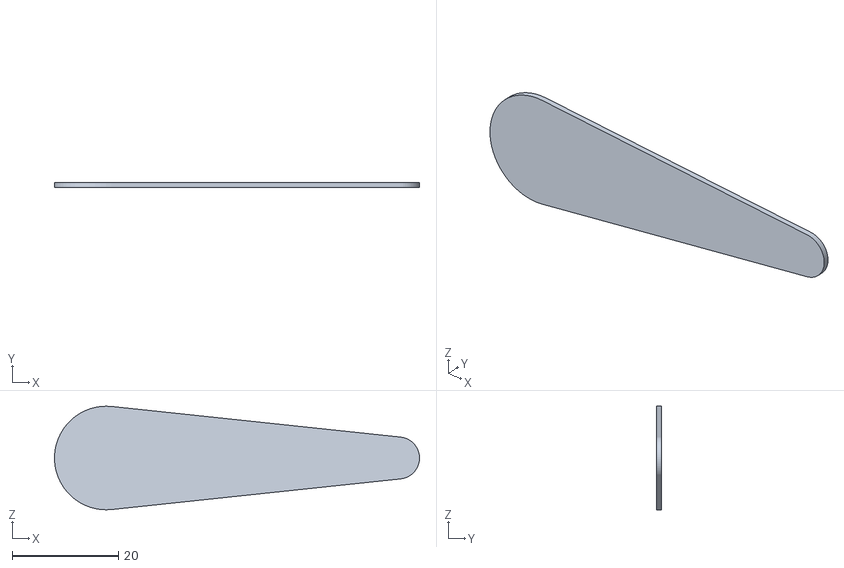
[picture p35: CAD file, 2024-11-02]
cad/3D/v1/lower-leg-accent.stl
68.7 x 1.00 x 19.5

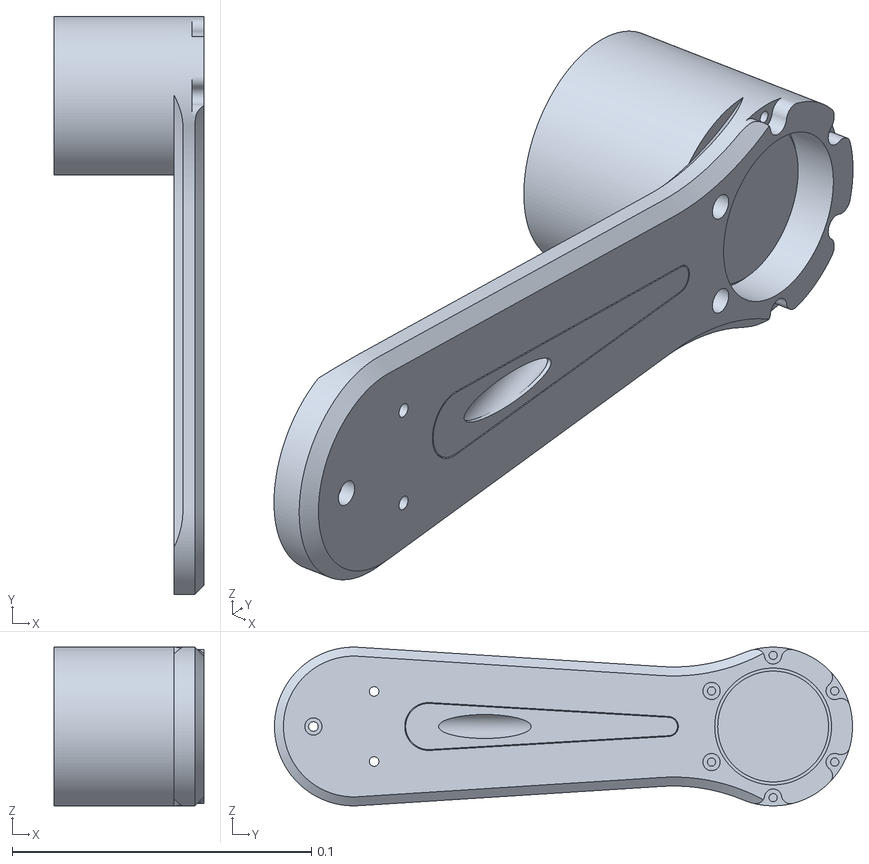
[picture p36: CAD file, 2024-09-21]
src/model/assets/upper-leg.stl
0.05 x 0.193 x 0.053

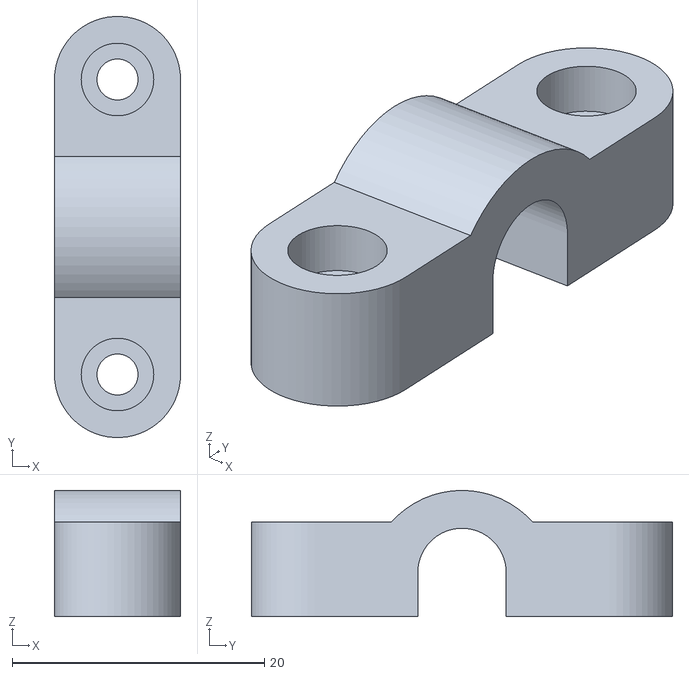
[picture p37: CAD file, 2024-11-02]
cad/3D/v1/splitloom-to-leg-clip.stl
10.0 x 33.4 x 10.0

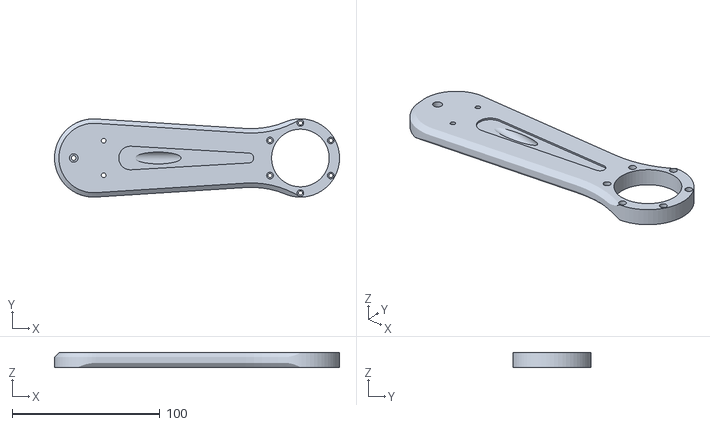
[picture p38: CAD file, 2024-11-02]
cad/3D/v1/upper-leg.stl
193.0 x 53.0 x 10.0

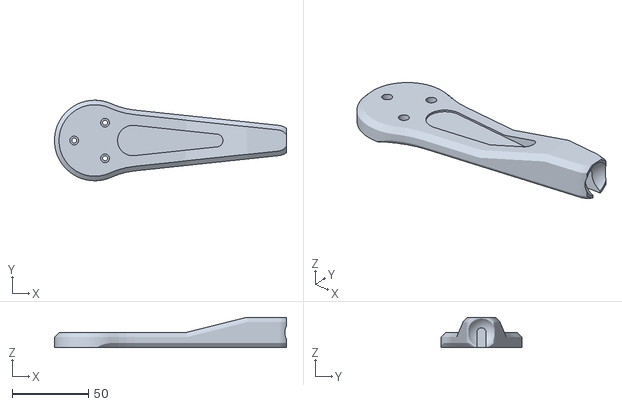
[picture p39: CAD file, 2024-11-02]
cad/3D/v1/lower-leg.stl
152.5 x 53.0 x 20.0

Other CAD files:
cad/2D/electropup.dwg
cad/3D/v1/hip-wire-clip.stl
cad/3D/v1/splitloom-clip.stl
cad/3D/v1/hip-motor-bracket-riser.stl
cad/3D/v1/hip-motor-bracket-base.stl

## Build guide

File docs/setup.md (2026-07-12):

# Setup

Read the entire guide prior to beginning the setup procress as this document may not be sequential order.

# Development PC (Ubuntu)

The development PC is used to display UI, Mujoco simulation, and charts as well as remote into the Raspberry Pi for code development.

## Setup VSCode
Install VSCode along with extensions:
- Remote Explorer

Connect to the Raspberry Pi (after setup) using Remove Explorer and install these extensions:
- Python

Select the virtual environment's interpreter:

Press `Ctrl+Shift+P` → "Python: Select Interpreter"  
Look for (or similar):  

> Python 3.13.5 (3.13.5) ~/.pyenv/versions/3.13.5/bin/python

Press `Ctrl+Shift+P` → "Reload Window"

---

# Raspberry Pi

Hardware: Raspberry Pi 5  

Using Raspberry Pi Imager, select **Raspberry Pi OS Lite, Bookworm 64-bit**  
Apply custom configuration:
- hostname: `electropup`
- username: `pi`
- password: `pi`
- SSID: `<your-wifi-credentials>`
- password: `<your-wifi-credentials>`

## SSH

(If the host is not found, try scanning for the IP using a tool like *Angry IP Scanner*.) 

Copy the development PC's keys to RPI:
```bash
ssh-copy-id pi@electropup.local
```

Login (should not prompt for password if keys are copied):
```bash
ssh pi@electropup.local
```

Update:
```bash
sudo apt update
```

Generate SSH key (press enter three times for defaults):
```bash
ssh-keygen
```

Get the public key:
```bash
cat ./.ssh/id_rsa.pub
```

Optional: Add public key to GitHub/GitLab/etc.

## Source

Install git:
```bash
sudo apt install -y git
```

Clone the ElectroPup repo:
```bash
git clone git@github.com:reubenstr/ElectroPup.git
```

## Python

Install dependencies:
```bash
sudo apt update
sudo apt install -y make build-essential libssl-dev zlib1g-dev libbz2-dev libreadline-dev libsqlite3-dev curl libncursesw5-dev xz-utils tk-dev libxml2-dev libxmlsec1-dev libffi-dev liblzma-dev git
```

Install pyenv:
```bash
curl https://pyenv.run | bash
```

Update `.bashrc`:

```bash
echo 'export PYENV_ROOT="$HOME/.pyenv"' >> ~/.bashrc
echo 'export PATH="$PYENV_ROOT/bin:$PATH"' >> ~/.bashrc
echo 'eval "$(pyenv init --path)"' >> ~/.bashrc
echo 'eval "$(pyenv init -)"' >> ~/.bashrc
```

Install Python:
```bash
pyenv install 3.13
```

Restart the terminal.  

Check version:
```bash
cd ./ElectroPup/src
python --version
```

Setup venv:
```bash
cd ./ElectroPup/src
python3.13 -m venv .venv
source .venv/bin/activate
pip install --upgrade pip
```

### Install Dependencies

```bash
sudo apt update
sudo apt install python3-gpiozero
sudo apt install upower
```
Run these commands while in the virtual environment from the above step.

```bash
cd ./ElectroPup/src
pip install -r requirements.txt
```

# CAN

CAN shield: [Waveshare 2-ch CAN HAT](https://www.waveshare.com/2-ch-can-hat.htm)

### Install bcm2835
```bash
cd ~
mkdir temp
cd temp

wget http://www.airspayce.com/mikem/bcm2835/bcm2835-1.60.tar.gz
tar zxvf bcm2835-1.60.tar.gz 
cd bcm2835-1.60/
sudo ./configure
sudo make
sudo make check
sudo make install
```

### Install WiringPi
```bash
wget https://files.waveshare.com/upload/8/8c/WiringPi-master.zip
sudo apt-get install unzip
unzip WiringPi-master.zip
cd WiringPi-master/
sudo ./build
```

Add these lines to `/boot/firmware/config.txt`

```bash
dtparam=spi=on
dtoverlay=mcp2515-can1,oscillator=16000000,interrupt=25
dtoverlay=mcp2515-can0,oscillator=16000000,interrupt=23
dtoverlay=spi-bcm2835-overlay
```

### Setup CAN
```bash
sudo ip link set can0 up type can bitrate 1000000
sudo ip link set can1 up type can bitrate 1000000
sudo ifconfig can0 txqueuelen 65536
sudo ifconfig can1 txqueuelen 65536
```

Check for interfaces:
```bash
ifconfig
```

### Loopback Test

Optional: check communications by connecting can0 and can1 together and running these commands.

```bash
sudo apt-get install can-utils
```

Terminal 1:
```bash
candump can0
```

Terminal 2:
```bash
cansend can1 000#11.22.33.44
cansend can1 141#8800000000000000
cansend can1 141#8000000000000000
```

# Gamepad

Assumes a Playstation 4 controller.  

Reset the controller by powering on the controller then pressing the button inside the hole on back rightside.  

On the Raspberry Pi

```bash
sudo bluetoothctl
scan on
```

Press and hold **PS + Share** until flashing.  
Example scan output:  

> [NEW] Device 84:30:95:48:0F:3C Wireless Controller

Pair and connect:
```bash
scan off
pair <mac-address>
trust <mac-address>
connect <mac-address>
devices
```

Power cycle controller.  

Optional test:
```bash
sudo apt-get install joystick
jstest /dev/input/js0
```

# Serial 

Serial is for the Auxillary board which is optional hardware.

Append to `/boot/firmware/config.txt`:
```bash
enable_uart=1
dtoverlay=uart0
```

# IMU

Enable I2C using `raspi-config`.  

```bash
sudo raspi-config
```

Scan for attached I2C hardware:
```bash
sudo apt install i2c-tools
ls /dev/i2c-*
i2cdetect -y 1
```

Or use the scanner script:
```bash
./src/system/hardware/i2c_scanner.py
```

BNO055 address is `0x28`.

# Run in Development Mode

Since the project uses virtual environments, shell scripts are used as helpers to start the virtual environments and start the Python scripts.

```bash
cd ./ElectroPup/src/ui
```

Run the UI server
```bash
sudo ./server.sh
```

Run the Heartbeat (if the Auxilary board is being used)
```bash
sudo ./heartbeat.sh
```

Run the main application
```bash
sudo ./main.sh --dev
```

The main application requires either the `--live` or the `--dev` argument

`--dev`: does not allow motors to enable and start in a walking gait

`--live`: allows motors to enable and start in a sitting pose.

### Other arugments

These following argments can be passed to stop, start, restart, and disable the main service as a helper during development

- --start
- --stop
- --restart
- --disable

# Install Services (Live Mode)

There are three services that will automatically run the main script, the server for the UI, and the heartbeat for the auxilary board.

Install the services

```bash
cd ./ElectroPup/src/setup
./install_main.sh
./install_server.sh
./install_heartbeat.sh

```

Check the status of a service (main service as an example)
```bash
sudo systemctl status main.service 
```

Stop a service
```bash
sudo systemctl stop main.service 
```

Start a service
```bash
sudo systemctl start main.service 
```

Restart a service
```bash
sudo systemctl restart main.service 
```

View services logs live
```bash
sudo journalctl -u main.service -f
```

## Wifi Client and Hotspot

To create a hotpot on the Raspberry Pi for SSH and UI access when not near the WiFi AP add the following environmental variables to .bashrc

```export ELECTROPUP_CLIENT_SSID="<your-wifi-ssid>"
export ELECTROPUP_CLIENT_PASS="<your-wifi-password>"
```

The gamepad keybind image shows the commands to create a hotspot and to connect back to the WiFi AP.

---

# Motor Zeroing

To zero the motors run the zeroing script

```bash
cd ./ElectroPup/src
sudo ./zero.sh
```

---

# UI

On development PC (Raspberry PI is capable of running but is slow for rapid development)

Install NVM:
```bash
curl -o- https://raw.githubusercontent.com/nvm-sh/nvm/v0.39.7/install.sh | bash
```

Check:
```bash
nvm --version
```

Install node.js and npm:
```bash
nvm install --lts
```
Install Yarn:
```bash
corepack enable
corepack prepare yarn@stable --activate
yarn --version
```

Install packages:
```bash
cd ./ElectroPup/src/ui
yarn install
```

Start app in development mode:
```bash
yarn web
```

Build app for web (exports to ./src/ui/dist):
```bash
npx web-build
```

---

# Simulation / Mujoco

On Desktop development PC  

Install mujoco:
```bash
pip install mujoco
```

Run viewer (no model):
```bash
python -m mujoco.viewer
```

Run viewer with ElectroPup scene:
```bash
python3 -m mujoco.viewer --mjcf=<path-to-scene>
python3 -m mujoco.viewer --mjcf=~/Desktop/projects/ElectroPup/src/model/scene.xml
```

[Mujoco API reference](https://mujoco.readthedocs.io/en/stable/APIreference/index.html)

---

# Tools

## Requirements

Create `requirements.txt`:

```bash
cd ./ElectroPup/src
```

All packages:
```bash
pip freeze > requirements.txt
```

Project-specific packages:
```bash
pip install pipreqs
pipreqs .
```

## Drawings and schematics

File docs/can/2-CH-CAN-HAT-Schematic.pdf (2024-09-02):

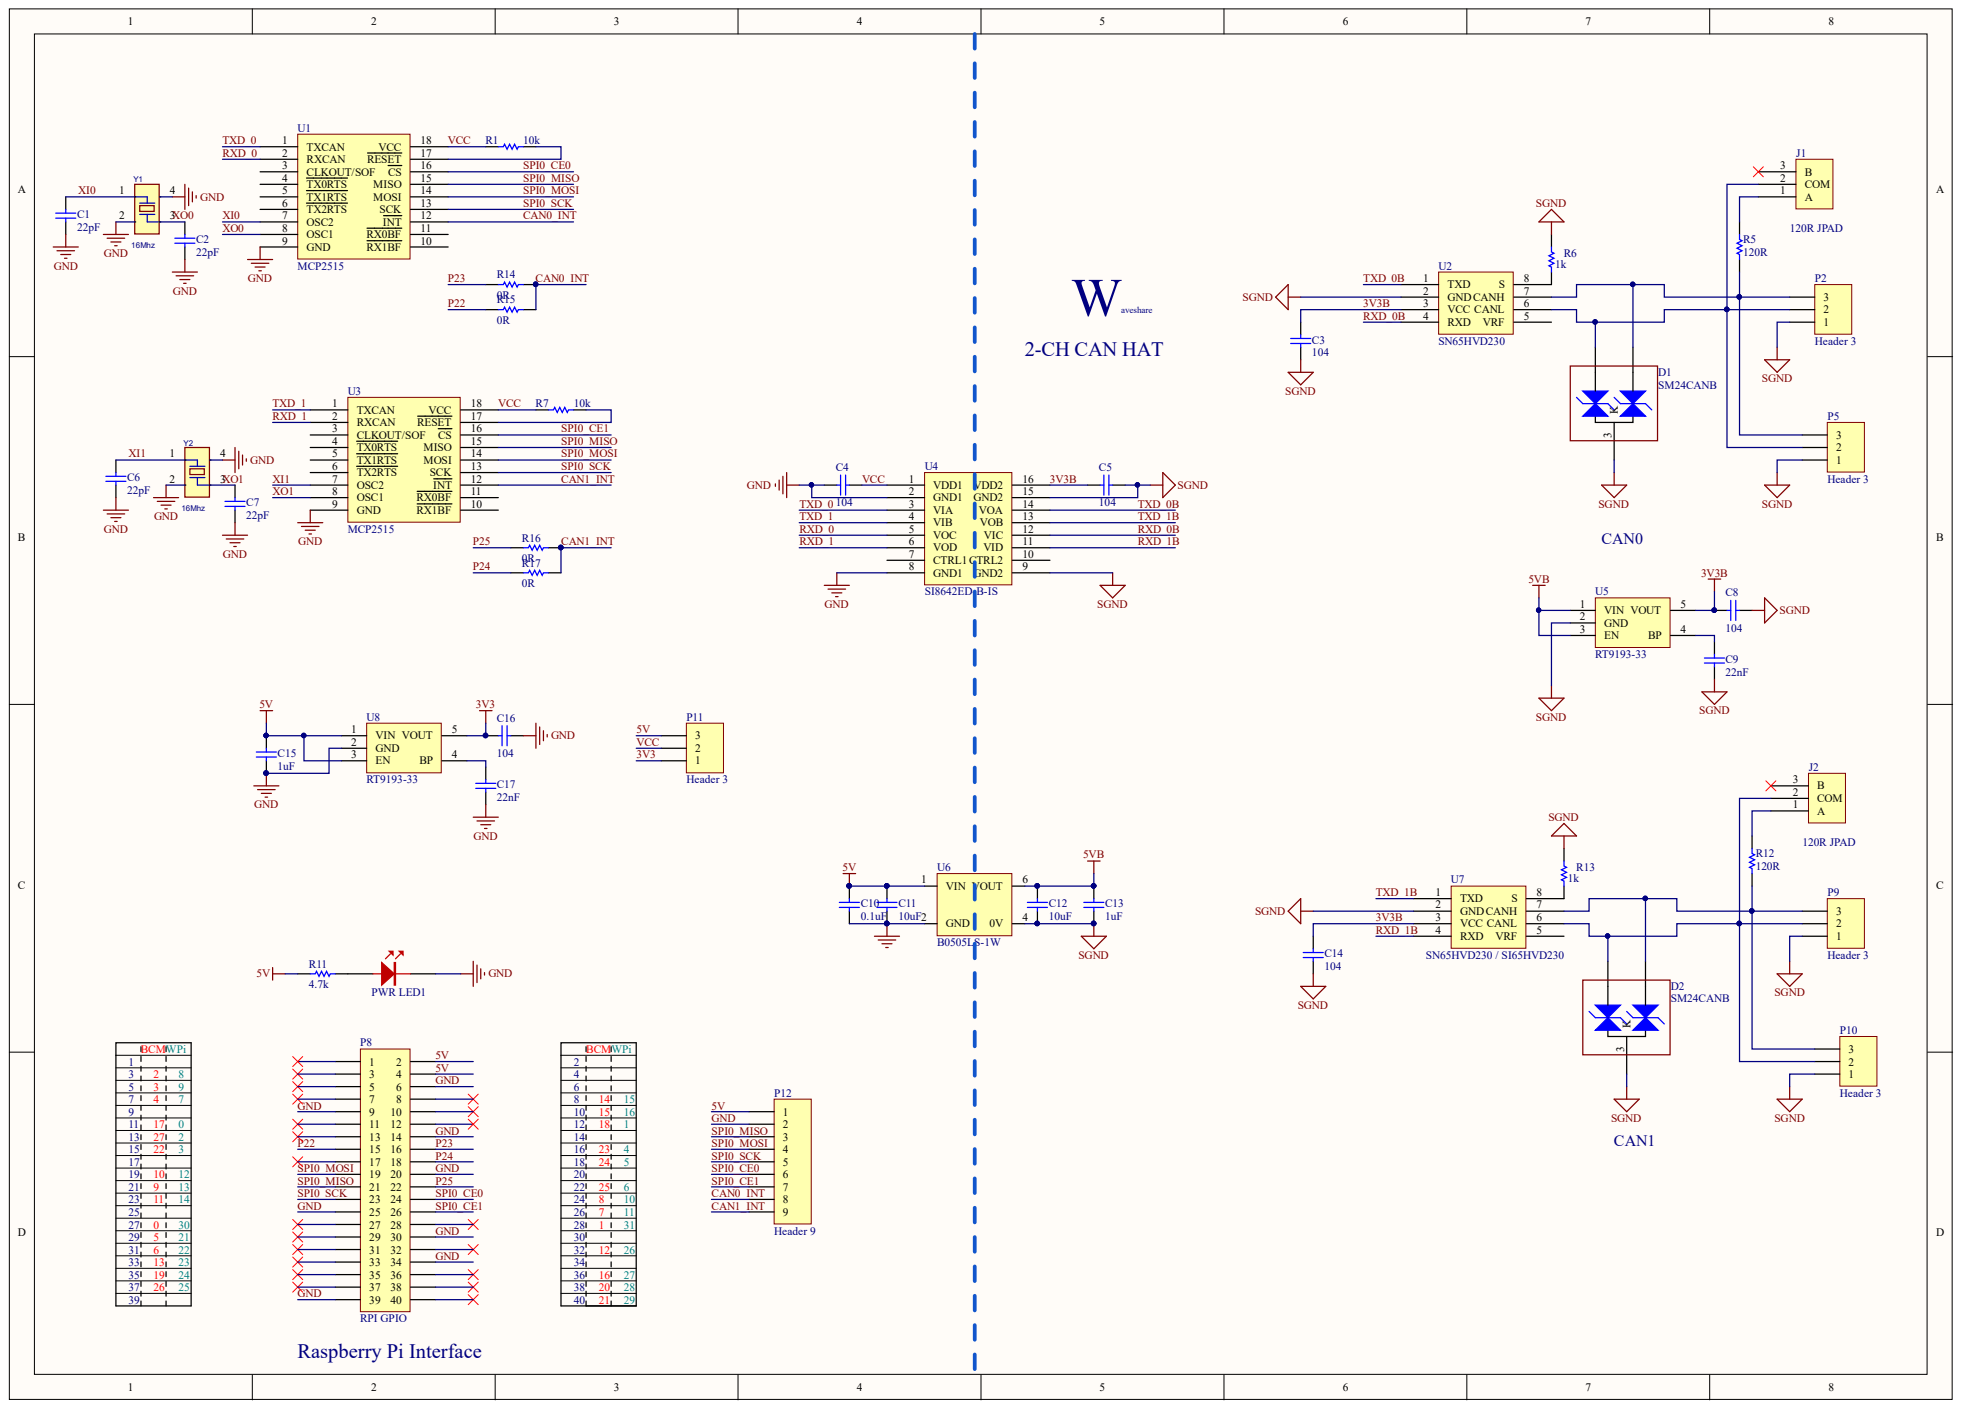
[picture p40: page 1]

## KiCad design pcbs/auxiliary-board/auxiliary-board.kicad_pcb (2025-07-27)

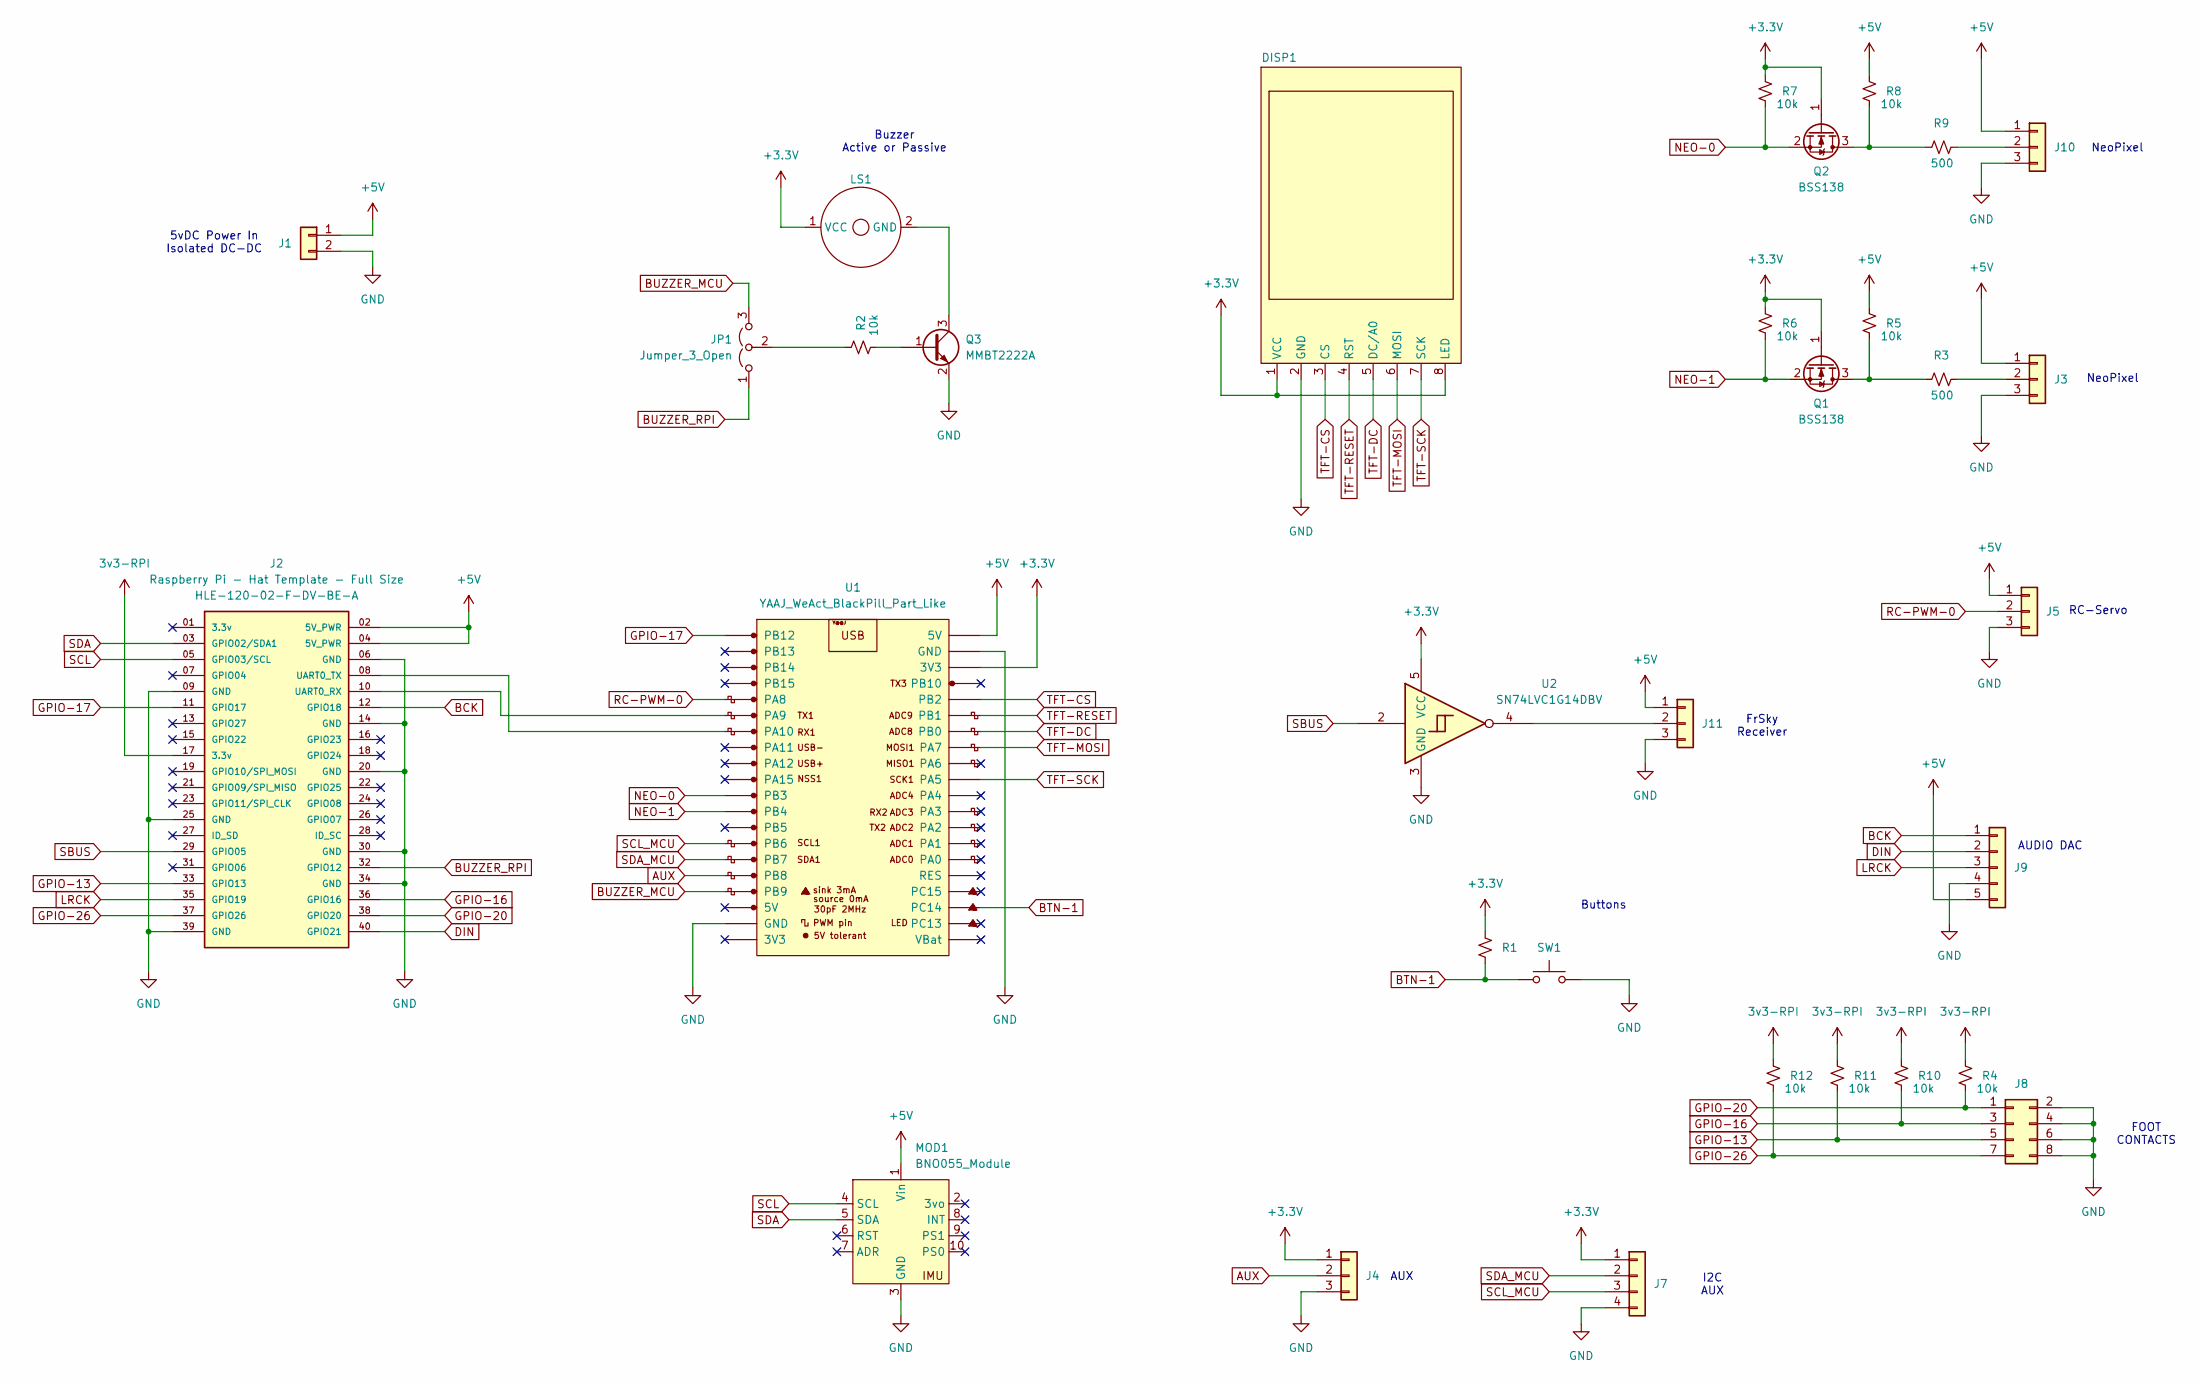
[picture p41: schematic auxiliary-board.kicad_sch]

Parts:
DISP1: LCD-Display-1.8-128x160-Hiletgo
J1: Conn_01x02; TerminalBlock_Phoenix_PT-1,5-2-3.5-H_1x02_P3.50mm_Horizontal
J2: Raspberry Pi - Hat Template - Full Size; Raspberry Pi - Hat Template - Full Size Extended
J3, J4, J5, J10, J11: Conn_01x03; JST_ZH_B3B-ZR_1x03_P1.50mm_Vertical
J7: Conn_01x04; JST_ZH_B4B-ZR_1x04_P1.50mm_Vertical
J8: Conn_02x04_Odd_Even; PinHeader_2x04_P2.54mm_Vertical
J9: Conn_01x05; JST_ZH_B5B-ZR_1x05_P1.50mm_Vertical
JP1: Jumper_3_Open; SolderJumper-3_P1.3mm_Open_Pad1.0x1.5mm
LS1: PB-09N23P-03Q_MAL
MOD1: BNO055_Module; BNO055 Module
Q1, Q2: BSS138; SOT-23
Q3: MMBT2222A; SOT-23
R1: R_Small_US; R_1206_3216Metric
R2, R4, R5, R6, R7, R8, R10, R11, R12: 10k; R_1206_3216Metric
R3, R9: 500; R_1206_3216Metric
SW1: SW_Push; SW_PUSH_6mm_H4.3mm
U1: YAAJ_WeAct_BlackPill_Part_Like; Blackpill WeAct
U2: SN74LVC1G14DBV; SOT-23-5

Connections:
3v3-RPI: J2.17 (3.3v), R4.2, R10.2, R11.2, R12.2
+3.3V: DISP1.1 (VCC), DISP1.8 (LED), J4.1, J7.1, LS1.1 (VCC), Q1.1 (G), Q2.1 (G), R1.2, R6.2, R7.2, U1.38 (3V3), U2.5 (VCC)
+5V: J1.1, J2.02 (5V_PWR), J2.04 (5V_PWR), J3.1, J5.1, J9.5, J10.1, J11.1, MOD1.1 (Vin), R5.2, R8.2, U1.40 (5V)
AUX: J4.2, U1.16 (PB8)
BCK: J2.12 (GPIO18), J9.1
BTN-1: R1.1, SW1.1, U1.23 (PC14)
BUZZER_MCU: JP1.3 (B), U1.17 (PB9)
BUZZER_RPI: J2.32 (GPIO12), JP1.1 (A)
DIN: J2.40 (GPIO21), J9.2
GND: DISP1.2 (GND), J1.2, J2.06 (GND), J2.09 (GND), J2.14 (GND), J2.20 (GND), J2.25 (GND), J2.30 (GND), J2.34 (GND), J2.39 (GND), J3.3, J4.3, J5.3, J7.4, J8.2, J8.4, J8.6, J8.8, J9.4, J10.3, J11.3, MOD1.3 (GND), Q3.2 (E), SW1.2, U1.19 (GND), U1.39 (GND), U2.3 (GND)
GPIO-13: J2.33 (GPIO13), J8.5, R11.1
GPIO-16: J2.36 (GPIO16), J8.3, R10.1
GPIO-17: J2.11 (GPIO17), U1.1 (PB12)
GPIO-20: J2.38 (GPIO20), J8.1, R4.1
GPIO-26: J2.37 (GPIO26), J8.7, R12.1
LRCK: J2.35 (GPIO19), J9.3
NEO-0: Q2.2 (S), R7.1, U1.11 (PB3)
NEO-1: Q1.2 (S), R6.1, U1.12 (PB4)
unnamed: J2.10 (UART0_RX), U1.6 (PA9)
unnamed: J2.08 (UART0_TX), U1.7 (PA10)
unnamed: J3.2, R3.2
unnamed: J10.2, R9.2
unnamed: J11.2, U2.4
unnamed: JP1.2 (C), R2.2
unnamed: LS1.2 (GND), Q3.3 (C)
unnamed: Q1.3 (D), R3.1, R5.1
unnamed: Q2.3 (D), R8.1, R9.1
unnamed: Q3.1 (B), R2.1
RC-PWM-0: J5.2, U1.5 (PA8)
SBUS: J2.29 (GPIO05), U2.2
SCL: J2.05 (GPIO03/SCL), MOD1.4 (SCL)
SCL_MCU: J7.3, U1.14 (PB6)
SDA: J2.03 (GPIO02/SDA1), MOD1.5 (SDA)
SDA_MCU: J7.2, U1.15 (PB7)
TFT-CS: DISP1.3 (CS), U1.36 (PB2)
TFT-DC: DISP1.5 (DC/A0), U1.34 (PB0)
TFT-MOSI: DISP1.6 (MOSI), U1.33 (PA7)
TFT-RESET: DISP1.4 (RST), U1.35 (PB1)
TFT-SCK: DISP1.7 (SCK), U1.31 (PA5)

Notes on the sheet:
Buzzer Active or Passive
AUDIO DAC
AUX
Buttons
FrSky Receiver
FOOT CONTACTS
NeoPixel
I2C AUX
RC-Servo
5vDC Power In Isolated DC-DC

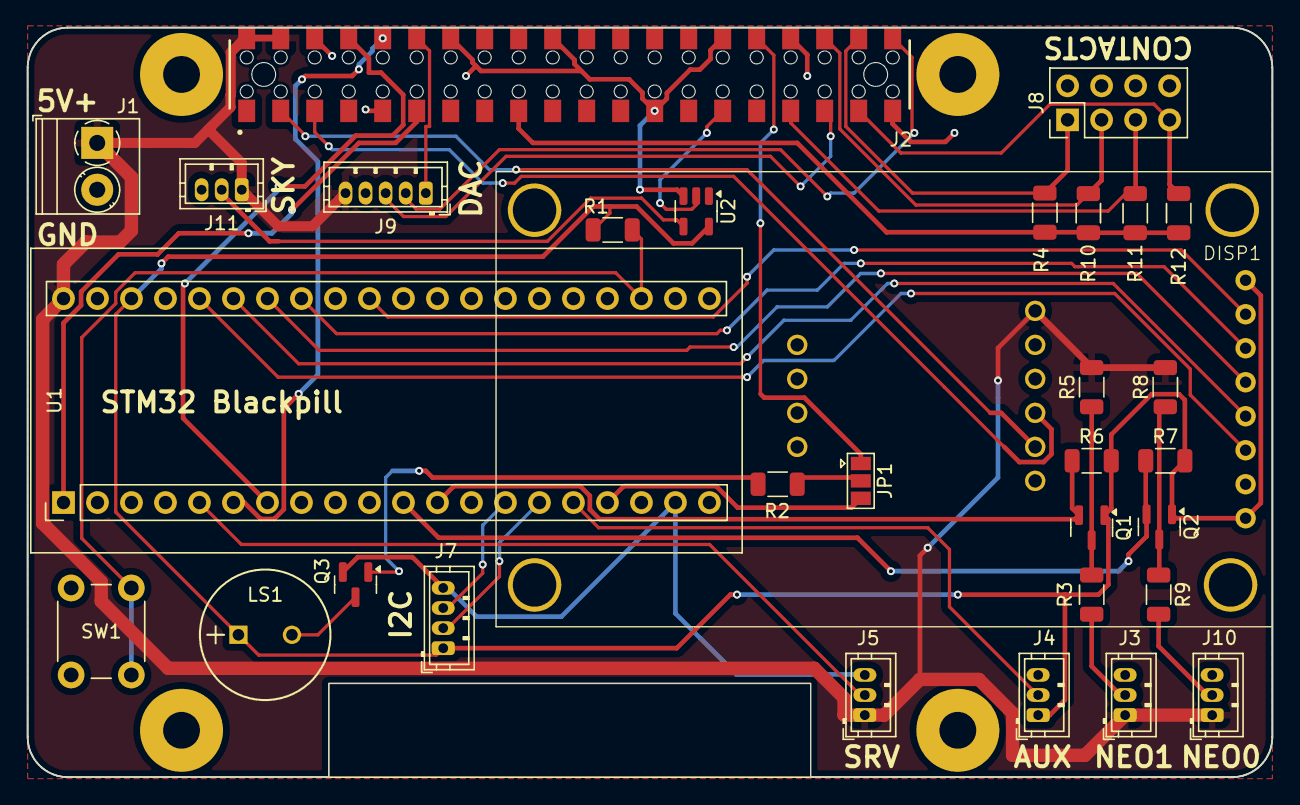
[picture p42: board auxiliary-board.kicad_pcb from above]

Board: 2 copper layers, 93.0 x 56.0 mm, 32 parts (1 on the bottom side), 39 nets.

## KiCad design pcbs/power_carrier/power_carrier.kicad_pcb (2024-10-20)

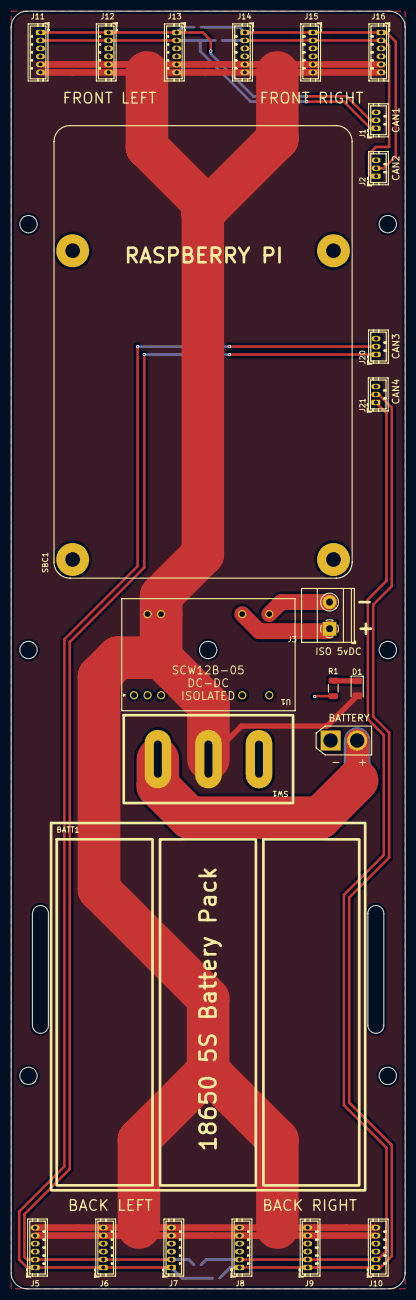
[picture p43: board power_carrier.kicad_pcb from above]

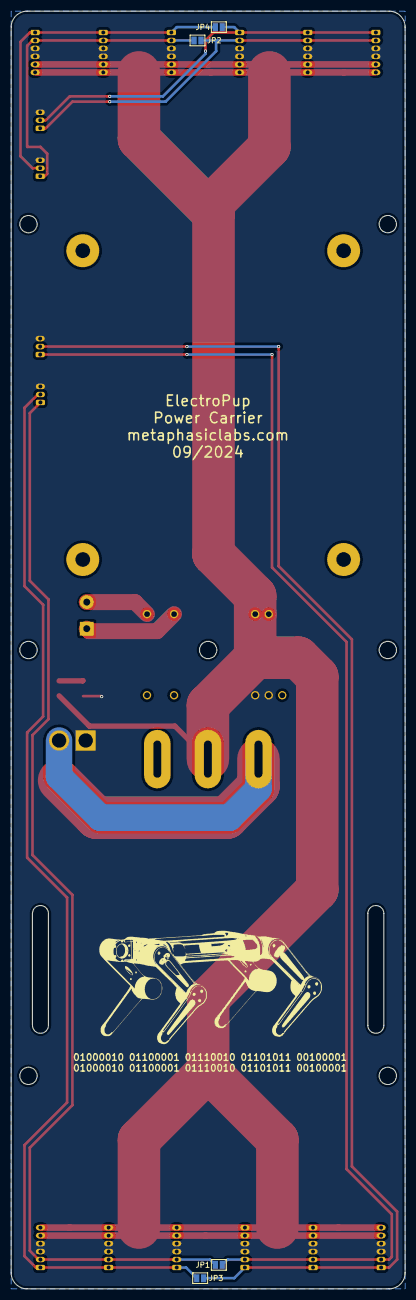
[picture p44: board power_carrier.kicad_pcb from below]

Board: 2 copper layers, 74.0 x 240.0 mm, 28 parts (4 on the bottom side), 14 nets.

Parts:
BATT1: 18650 6S Battery Pack - Footprint Only
D1: LED; LED_1206_3216Metric
J1, J2, J20, J21: Conn_01x03; JST_ZH_B3B-ZR_1x03_P1.50mm_Vertical
J3: Conn_01x02; TerminalBlock_Phoenix_MKDS-1,5-2_1x02_P5.00mm_Horizontal
J4: AMASS Connector; AMASS_XT30U-M_1x02_P5.0mm_Vertical
J5, J6, J7, J8, J9, J10, J11, J12, J13, J14, J15, J16: Conn_01x06; JST_ZH_B6B-ZR_1x06_P1.50mm_Vertical
JP1, JP2, JP3, JP4: SolderJumper_2_Open; SolderJumper-2_P1.3mm_Open_Pad1.0x1.5mm
R1: R_Small_US; R_1206_3216Metric
SBC1: RASPBERRY_PI_4B - Footprint Only
SW1: SW_SPST; CRE22F4DBBNE
U1: SCW12B-05; SCW12B-05_MWU

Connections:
+BATT: D1.2 (A), J5.5, J5.6, J6.5, J6.6, J7.5, J7.6, J8.5, J8.6, J9.5, J9.6, J10.5, J10.6, J11.5, J11.6, J12.5, J12.6, J13.5, J13.6, J14.5, J14.6, J15.5, J15.6, J16.5, J16.6, SW1.2 (B), U1.22 (+VIN), U1.23 (+VIN)
/CAN1 HIGH: J1.1, J11.2, J12.2, J13.2, JP2.1 (A)
/CAN1 LOW: J1.2, J11.1, J12.1, J13.1, JP4.1 (A)
/CAN2 HIGH: J2.1, J14.2, J15.2, J16.2, JP2.2 (B)
/CAN2 LOW: J2.2, J14.1, J15.1, J16.1, JP4.2 (B)
/CAN3 HIGH: J5.2, J6.2, J7.2, J20.1, JP1.1 (A)
/CAN3 LOW: J5.1, J6.1, J7.1, J20.2, JP3.1 (A)
/CAN4 HIGH: J8.2, J9.2, J10.2, J21.1, JP1.2 (B)
/CAN4 LOW: J8.1, J9.1, J10.1, J21.2, JP3.2 (B)
/ISO 5vDC GND: J3.2, U1.14 (+VOUT)
/ISO 5vDC+: J3.1, U1.16 (-VOUT)
GND: J1.3, J2.3, J4.1 (-), J5.3, J5.4, J6.3, J6.4, J7.3, J7.4, J8.3, J8.4, J9.3, J9.4, J10.3, J10.4, J11.3, J11.4, J12.3, J12.4, J13.3, J13.4, J14.3, J14.4, J15.3, J15.4, J16.3, J16.4, J20.3, J21.3, R1.2, U1.2 (-VIN), U1.3 (-VIN)
unnamed: D1.1 (K), R1.1
unnamed: J4.2 (+), SW1.1 (A)

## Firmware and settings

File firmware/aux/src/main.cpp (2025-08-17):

/*
  Project:
    Auxiliary Board for ElectroPup quadruped.
    Drives a LCD display, buzzer, Neopixels strips, RC servo, and more.

  MCU:
    STM32F401CC

  Dev. Board:
    WeAct Black Pill:
      https://stm32-base.org/boards/STM32F401CCU6-WeAct-Black-Pill-V1.2.html
      https://www.aliexpress.us/item/3256801269871873.html
      https://www.amazon.com/dp/B09MLHYF89/

    Alternatives (Blue Pill and other Black Pill):
      STM32F103C8T6
      STM32F411CEU6

  Display:
    The TFT_eSPI library (LCD driver) configuration is located in platformio.ini
    ST7735 128*160 1.8"
    https://www.aliexpress.us/item/3256806134563059.html

  PCB/Schematics:
    See PCBs directory in the the ElectroPup repo for schematics:
      https://github.com/reubenstr/ElectroPup

  TODO:
    System error bools and strings are magical; should they be made into their own enum and/or class?
 */

#include <Arduino.h>
#include <math.h>
#include <SPI.h>
#include "TFT_eSPI.h"
#include "OneButton.h"
#include "buzzer.h"
#include "neopixels.h"
#include "main.h"

TFT_eSPI tft = TFT_eSPI();
Buzzer buzzer(PIN_MCU_BUZZER);
OneButton button(PIN_BTN_1, true);
Neopixels neopixels(PIN_NEO_0, PIN_NEO_1);

Page page = Page::SYSTEM;
const int cornerRadiusPx{2};

uint32_t lastMessageReceivedMillis;

///////////////////////////////////////////////////////////////////////////////
// Program
///////////////////////////////////////////////////////////////////////////////

void HeartbeatLed()
{
  static uint32_t start{0};
  static bool toggle{false};

  if (millis() - start > heartbeatBlinkRateMs)
  {
    start = millis();
    digitalWrite(LED_BUILTIN, !digitalRead(LED_BUILTIN));
  }
}

// Black Pill STM32 onboard button.
void CheckUserButton()
{
  if (digitalRead(USER_BTN) == LOW)
  {
    Serial.println("Blackpill onboard button is pressed.");
    delay(500);
  }
}

///////////////////////////////////////////////////////////////////////////////
// Display
///////////////////////////////////////////////////////////////////////////////

void InitDisplay()
{
  tft.begin();
  delay(25);
  tft.setRotation(2);
  delay(25);
  tft.fillScreen(TFT_BLACK);
  tft.setTextDatum(CC_DATUM);

  UpdateDisplay(true);
}

void UpdateDisplay(bool forceRefresh = false)
{

  // TODO: force refresh on page change

  if (page == Page::SPLASH)
  {
    DisplaySplashPage();
  }
  else if (page == Page::SYSTEM)
  {
    DisplaySystemPage(forceRefresh);
  }
  else if (page == Page::BATTERY)
  {
    DisplayBatteryPage(forceRefresh);
  }
}

void DisplaySplashPage()
{
}

void DisplaySystemPage(bool forceRefresh = false)
{

  // SBC (RPI) errors take precedence of colors and requires refreshes.
  bool isSbcError = getValueFromStatusString("RPI") || getValueFromStatusString("SFT");
  static bool previousSbcStatus;
  if (previousSbcStatus != isSbcError)
  {
    previousSbcStatus = isSbcError;
    forceRefresh = true;
  }

  if (forceRefresh)
  {
    tft.setTextFont(1);
    tft.setTextSize(1);
    tft.setTextColor(TFT_BLACK);
  }

  {
    // SYSTEM
    static bool previousSystemStatus[numSystemStatus];
    const int xOffset = 7;
    const int yOffset = 5;
    const int xMult = 29;
    const int yMult = 24;
    int index = 0;
    for (int x = 0; x < 4; x++)
    {
      for (int y = 0; y < 3; y++)
      {
        bool hasError = systemErrors[index];

        if (previousSystemStatus[index] != hasError || forceRefresh)
        {
          previousSystemStatus[index] = hasError;

          uint32_t color = hasError ? TFT_RED : TFT_GREEN;

          if (isSbcError)
          {
            if ((index != getIndexFromStatusString("RPI") && !hasError) || (index != getIndexFromStatusString("SFT") && !hasError))
            {
              color = TFT_DARKGREY;
            }
          }
          else if (index == getIndexFromStatusString("JOY") && systemValues.joystickBatteryPercentage < systemLowBatteryPercentThreashold)
          {    
            color = TFT_YELLOW;
          }

          tft.fillRoundRect(x * xMult + xOffset, y * yMult + yOffset, 26, 20, cornerRadiusPx, color);
          tft.drawString(systemStatusStrings[index], x * xMult + xOffset + 13, y * yMult + 10 + yOffset);
        }
        index++;
      }
    }
  }

  {
    // MOTORS
    static bool previousMotorOns[numMotors];
    static bool previousMotorErrors[numMotors];
    const int xOffset = 7;
    const int yOffset = 86;
    const int xMult = 29;
    const int yMult = 24;

    int index = 0;
    for (int x = 0; x < 4; x++)
    {
      for (int y = 0; y < 3; y++)
      {
        bool motorOn = motorOns[index];
        bool hasError = motorErrors[index];

        if (previousMotorOns[index] != motorOn || previousMotorErrors[index] != hasError || forceRefresh)
        {
          previousMotorOns[index] = motorOn;
          previousMotorErrors[index] = hasError;
          uint32_t color = hasError ? TFT_RED : motorOn ? TFT_GREEN
                                                        : TFT_BLUE;

          if (isSbcError)
            color = TFT_DARKGREY;

          tft.fillRoundRect(x * xMult + xOffset, y * yMult + yOffset, 26, 20, cornerRadiusPx, color);
          tft.drawString(motorStatusStrings[index], x * xMult + xOffset + 13, y * yMult + 10 + yOffset);
        }
        index++;
      }
    }
  }
}

void DisplayBatteryPage(bool forceRefresh = false)
{
}

///////////////////////////////////////////////////////////////////////////////
// Communications
///////////////////////////////////////////////////////////////////////////////

void InitMessageComms()
{
  Serial1.begin(115200);
  Serial1.setTimeout(10);
}

// TODO: DRY crc error message.
void CheckForMessage()
{
  uint8_t data[1024];

  size_t numBytes = Serial1.readBytes((uint8_t *)&data, sizeof(data));
  if (numBytes)
  {

    MessageType messageType = static_cast<MessageType>(data[0]);

    if (messageType == MessageType::STATUS)
    {
      if (numBytes != sizeof(StatusMessage))
      {
        Serial.printf("[Comms] error, status message length does not match. Received: %u, expected: %u\n", numBytes, sizeof(StatusMessage));
        return;
      }

      StatusMessage message;
      memcpy(&message, data, sizeof(StatusMessage));
      uint32_t crc32Result = crc32((uint8_t *)&message, sizeof(StatusMessage) - sizeof(uint32_t));
      if (crc32Result == message.crc32)
      {
        lastMessageReceivedMillis = millis();

        setValueFromStatusString("JOY", message.statusData.joystickError);
        setValueFromStatusString("LIM", message.statusData.physicalLimitError);
        setValueFromStatusString("JA", message.statusData.jointAngleError);
        setValueFromStatusString("IK", message.statusData.inverseKinematicsError);
        setValueFromStatusString("CAN", message.statusData.canError);
        setValueFromStatusString("OTe", message.statusData.overTemperatureError);
        setValueFromStatusString("UVo", message.statusData.underVoltageError);
        setValueFromStatusString("MCo", message.statusData.motorCommunicationError);
        setValueFromStatusString("IMU", message.statusData.imuError);
        setValueFromStatusString("BAT", message.statusData.lowBattery);

        for (int i = 0; i < numMotors; i++)
        {
          motorOns[i] = message.statusData.motorOns[i];
          motorErrors[i] = message.statusData.motorErrors[i];
        }

        systemValues.batteryVoltage = message.statusData.batteryVoltage;
        systemValues.joystickBatteryPercentage = message.statusData.joystickBatteryPercentage;
      }
      else
      {
        Serial.printf("Message CRC32 is invalid! Message CRC32: %X, calculated CRC32: %X \n", message.crc32, crc32Result);
      }
    }
    else if (messageType == MessageType::PLAY_SOUND)
    {
      if (numBytes != sizeof(PlaySoundMessage))
      {
        Serial.printf("[Comms] error, play sound message length does not match. Received: %u, expected: %u\n", numBytes, sizeof(PlaySoundMessage));
        return;
      }

      PlaySoundMessage message;
      memcpy(&message, data, sizeof(PlaySoundMessage));
      uint32_t crc32Result = crc32((uint8_t *)&message, sizeof(PlaySoundMessage) - sizeof(uint32_t));
      if (crc32Result == message.crc32)
      {
        if (message.sequenceId > (int)Sequence::NONE && message.sequenceId < (int)Sequence::NUM_SOUNDS)
        {
          buzzer.play((Sequence)message.sequenceId);
        }
      }
      else
      {
        Serial.printf("Message CRC32 is invalid! Message CRC32: %X, calculated CRC32: %X \n", message.crc32, crc32Result);
      }
    }
    else
    {
      Serial.printf("[Comms] error, received unknown message type: %u\n", (int)messageType);
    }
  }
}

void CheckCommsTimeout()
{
  if (millis() - lastMessageReceivedMillis > noCommsTimeoutMs)
  {
    setValueFromStatusString("SFT", true);
  }
  else
  {
    setValueFromStatusString("SFT", false);
  }
}

///////////////////////////////////////////////////////////////////////////////
// Calculations
///////////////////////////////////////////////////////////////////////////////

float CalcBatteryPercent()
{
  // https://electronics.stackexchange.com/questions/435837/calculate-battery-percentage-on-lipo-battery
  return 123 - (123 / pow(1 + pow(systemValues.batteryVoltage / 3.7, 80), 0.165));
}

bool IsLowBattery()
{
  return CalcBatteryPercent() < systemLowBatteryPercentThreashold;
}

///////////////////////////////////////////////////////////////////////////////
// Misc.
///////////////////////////////////////////////////////////////////////////////

// Raspberry Pi sends a heartbeat as square wave changing state every 0.250 seconds.
void CheckRpiHeartbeat()
{
  static bool previousHeartbeatState{true};
  static bool rpiHasError{true};
  static bool previousRpiHasError{true};
  static uint32_t start{0};

  if (digitalRead(PIN_RPI_HEARTBEAT) != previousHeartbeatState)
  {
    previousHeartbeatState = digitalRead(PIN_RPI_HEARTBEAT);
    start = millis();
    rpiHasError = false;
  }

  if (millis() - start > rpiHeartbeatTimeoutMs)
  {
    rpiHasError = true;
  }

  if (previousRpiHasError != rpiHasError)
  {
    previousRpiHasError = rpiHasError;

    setValueFromStatusString("RPI", rpiHasError);

    if (rpiHasError)
      buzzer.play(Sequence::RPI_OFF);
    else
      buzzer.play(Sequence::RPI_ON);
  }
}

void ProcessNeopixels()
{
  static bool inStartState{true};

  bool error = false;
  for (int i = 0; i < numSystemStatus; i++)
  {
    if (systemErrors[i])
      error = true;
  }

  // Don't change starting pattern until all errors are clear,
  // which means the RPI has booted and is ready.
  if (!error)
  {
    inStartState = false;
  }

  if (inStartState)
  {
    neopixels.setMode(PixelMode::SPARKLE, PixelColor::RED);
  }
  else
  {
    if (error)
    {
      neopixels.setMode(PixelMode::ERROR, PixelColor::RED);
    }
    else
    {
      bool allMotorsOn{true};
      for (int i = 0; i < numMotors; i++)
      {
        if (!motorOns[i])
          allMotorsOn = false;
      }
      if (allMotorsOn)
        neopixels.setMode(PixelMode::RIDER, PixelColor::GREEN);
      else
        neopixels.setMode(PixelMode::RIDER, PixelColor::BLUE);
    }
  }

  neopixels.tick();
}

///////////////////////////////////////////////////////////////////////////////
// Handle Button Inputs
///////////////////////////////////////////////////////////////////////////////

void btnClick(void *oneButton)
{
  Serial.println("btnClick");

  buzzer.play(Sequence::BTN_BEEP_SHORT);
}

void btnDoubleClick(void *oneButton)
{
  Serial.println("btnDoubleClick");
}

void btnLongPressStart(void *oneButton)
{
  ShutDownMessage message;
  uint32_t crc32Result = crc32((uint8_t *)&message, sizeof(ShutDownMessage) - sizeof(uint32_t));
  message.crc32 = crc32Result;
  Serial1.write((uint8_t *)&message, sizeof(ShutDownMessage));
}

///////////////////////////////////////////////////////////////////////////////
// Entry
///////////////////////////////////////////////////////////////////////////////

void setup()
{
  Serial.begin(115200);

  pinMode(LED_BUILTIN, OUTPUT);
  pinMode(USER_BTN, INPUT_PULLUP);
  pinMode(PIN_BTN_1, INPUT_PULLUP);
  pinMode(PIN_RPI_HEARTBEAT, INPUT);

  // Expected errors at startup; prevents sound from starting during init.
  setValueFromStatusString("RPI", true);
  setValueFromStatusString("SFT", true);

  button.attachClick(btnClick, &button);
  button.attachDoubleClick(btnDoubleClick, &button);
  button.attachLongPressStart(btnLongPressStart, &button);
  button.setPressMs(byteLongPressActivationMs);
  button.setClickMs(100);

  neopixels.init();

  InitMessageComms();

  InitDisplay();

  buzzer.play(Sequence::MCU_STARTUP);
}

///////////////////////////////////////////////////////////////////////////////
// Main Loop
///////////////////////////////////////////////////////////////////////////////

void loop()
{
  HeartbeatLed();

  CheckUserButton();

  CheckForMessage();

  CheckCommsTimeout();

  CheckRpiHeartbeat();

  UpdateDisplay();

  buzzer.tick();

  button.tick();

  ProcessNeopixels();
}

/*
 if (display == Display::Splash)
  {
    tft.pushImage(0, 0, splashWidth, splashHeight, splash);
  }
  else if (display == Display::SelectDifficulty)
  {
    Logo bit array created using Lcd Image Converter
    https://sourceforge.net/projects/lcd-image-converter/
    Use the following conversion settings:
    Type: Color
    Block Size: 16 bit
    Byte Order: Big-Endian
    Either "Convert" and save the file to copy the array into this file,
    or copy the array from the "Preview" option in the Conversion options window.
*/

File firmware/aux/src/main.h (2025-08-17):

///////////////////////////////////////////////////////////////////////////////
// Pins
///////////////////////////////////////////////////////////////////////////////

#define PIN_BTN_1 PC14
#define PIN_RPI_HEARTBEAT PB12
#define PIN_MCU_BUZZER PB9
#define PIN_NEO_0 PB3
#define PIN_NEO_1 PB4

///////////////////////////////////////////////////////////////////////////////
// Timings
///////////////////////////////////////////////////////////////////////////////

const uint32_t heartbeatBlinkRateMs{250};
const uint32_t noCommsTimeoutMs{1000};
const uint32_t rpiHeartbeatTimeoutMs{250};
const uint32_t byteLongPressActivationMs{3000};

///////////////////////////////////////////////////////////////////////////////
// General
///////////////////////////////////////////////////////////////////////////////

const float gamepadLowBatteryPercentThreashold{0.25};
const float systemLowBatteryPercentThreashold{0.25};

///////////////////////////////////////////////////////////////////////////////
// Display
///////////////////////////////////////////////////////////////////////////////

enum class Page
{
    SPLASH,
    SYSTEM,
    BATTERY
};

const int numSystemStatus{12};
const char *systemStatusStrings[numSystemStatus] = {"RPI", "SFT", "JOY", "LIM", "JA", "IK", "CAN", "OTe", "UVo", "MCo", "IMU", "BAT"};
const char *motorStatusStrings[] = {"FLA", "FLH", "FLK", "FRA", "FRH", "FRK", "BLA", "BLH", "BLK", "BRA", "BRH", "BRK"};

///////////////////////////////////////////////////////////////////////////////
// Message and Data Structs
///////////////////////////////////////////////////////////////////////////////

bool systemErrors[numSystemStatus];

const int numMotors{12};
bool motorOns[numMotors];
bool motorErrors[numMotors];

struct SystemValues
{
    float batteryVoltage{0};
    float joystickBatteryPercentage{0};
} systemValues;

#pragma pack(1)
struct StatusData
{
    bool joystickError;
    bool physicalLimitError;
    bool jointAngleError;
    bool inverseKinematicsError;
    bool canError;
    bool overTemperatureError;
    bool underVoltageError;
    bool motorCommunicationError;
    bool imuError;
    bool lowBattery;

    bool motorOns[numMotors];
    bool motorErrors[numMotors];

    float batteryVoltage;
    float joystickBatteryPercentage;
};

enum class MessageType : uint8_t
{
    STATUS = 0,
    PLAY_SOUND,
    SHUTDOWN_RPI
};

#pragma pack(1)
struct StatusMessage
{
    MessageType messageType;
    StatusData statusData;
    uint32_t crc32;
};

#pragma pack(1)
struct PlaySoundMessage
{
    MessageType messageType;
    uint8_t sequenceId;
    uint32_t crc32;
};

#pragma pack(1)
struct ShutDownMessage
{
    MessageType messageType;
    uint32_t crc32;

    ShutDownMessage()
    {
        messageType = MessageType::SHUTDOWN_RPI;
    }
};

///////////////////////////////////////////////////////////////////////////////
// Prototypes
///////////////////////////////////////////////////////////////////////////////

void InitDisplay();
void UpdateDisplay(bool forceRefresh);
void DisplaySplashPage();
void DisplaySystemPage(bool forceRefresh);
void DisplayBatteryPage(bool forceRefresh);

bool IsLowBattery();
bool IsError();

///////////////////////////////////////////////////////////////////////////////
// Helpers
///////////////////////////////////////////////////////////////////////////////

// TODO: an assert of other warning should be applied of the string is not found.

int getIndexFromStatusString(const char *status)
{
    for (int i = 0; i < numSystemStatus; i++)
    {
        if (strcmp(status, systemStatusStrings[i]) == 0)
        {
            return i;
        }
    }
    return -1;
}

int getValueFromStatusString(const char *status)
{
    int index = getIndexFromStatusString(status);

    if (index != -1)
        return systemErrors[index];
    else
        return false;
}

void setValueFromStatusString(const char *status, bool state)
{
    int index = getIndexFromStatusString(status);

    if (index != -1)
        systemErrors[index] = state;
}

///////////////////////////////////////////////////////////////////////////////
// CRC
///////////////////////////////////////////////////////////////////////////////

uint32_t crc32(uint8_t *data, int length)
{
    const uint32_t POLYNOMIAL = 0x04C11DB7;
    uint32_t crc = 0xFFFFFFFF;

    for (size_t i = 0; i < length; i++)
    {
        crc ^= data[i] << 24;
        for (int j = 0; j < 8; ++j)
        {
            if (crc & 0x80000000)
            {
                crc = (crc << 1) ^ POLYNOMIAL;
            }
            else
            {
                crc <<= 1;
            }
            crc &= 0xFFFFFFFF;
        }
    }
    return crc ^ 0xFFFFFFFF;
}

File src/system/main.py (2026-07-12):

#!/usr/bin/env python3
import os
import queue
import argparse
import traceback
from queue import Queue
from time import sleep, time
from rich import print  # Overrides print and injects colors
from typing import Dict, List

from quadruped.quad import Quad
from quadruped.gait_planner import Gait
from quadruped.interfaces import LegName, JointName, AngleUnits, MotionState
from quadruped.motion import Motion
from quadruped.interfaces import OpMode, Status
from quadruped.parameters.ik_parameters import IKParameters
from hardware.hardware import Hardware
from motors.motors import Motor, Motors
from motors.interfaces import MotorName, MotorSpeeds
from auxiliary.aux import Aux, AuxMessage, Sequence
from utilities.utilities import *
from utilities.wifi import Wifi
from utilities.service import ServiceCommand, service_action
from input.interfaces import InputCommand, InputMode
from input.gamepad import Gamepad
from input.touch import Touch
from input.input import Input
from status import SystemStatus
from forwarder import Forwarder


"""
    ElectroPup main application.
"""


class Main:
    def __init__(self, mode: OpMode):
        self.op_mode: OpMode = mode 

        print(f"[Main] starting in operation mode: {self.op_mode}")

        self.command_queue = Queue()

        self.wifi = Wifi()
        self.hardware = Hardware()      
        self.motion = Motion(op_mode=self.op_mode)
        self.forwarder = Forwarder()
        self.aux = Aux()
        self.gamepad = Gamepad(self.command_queue)
        self.touch = Touch(self.command_queue)

        self.main_loop_rate_seconds = 0.010
        self.main_loop_time: float = 0
        self.main_loop_completion_time_ms: float = 0

        self.battery_voltage: float = 0
        self.low_battery_voltage_threadhold: float = 19.8
        self.low_battery_alert_rate_seconds: float = 30
        self.low_battery_last_alert_time: float = time()

        self.input_mode: InputMode = InputMode.GAMEPAD
         
    ###############################################################################
    # Main Loop
    ###############################################################################

    def run(self):
        while True:

            self.get_commands()

            self.update_inputs()

            self.check_low_battery()

            self.process_aux()

            self.forward_states()

            self.sleep_loop()

    ###############################################################################
    # Loop Methods
    ###############################################################################

    def get_commands(self):
        command = None
        try:
            command = self.command_queue.get_nowait()
        except queue.Empty:
            pass

        if command is not None:
            self.process_command(command)
    
    
    def update_inputs(self):
        self.motion.set_ik_parameters(self.get_ik_parameters())
        self.motion.set_motion_parameters(self.get_motion_parameters())

    def check_low_battery(self):
        if self.battery_voltage > 0 and self.battery_voltage < self.low_battery_voltage_threadhold:
            if time() - self.low_battery_last_alert_time > self.low_battery_alert_rate_seconds:
                self.low_battery_last_alert_time = time()             
                self.aux.play_sound(Sequence.LOW_BATTERY)

    def process_aux(self):
        """
        Check for commands and send latest status data to Auxiliary Board.
        """
        message = AuxMessage()
        message.joint_angle_error = self.motion.get_quad().get_joint_angle_error()
        message.inverse_kinematics_error = self.motion.get_quad().get_ik_error()
        message.joystick_error = self.gamepad.is_connected() == False
        message.can_error = self.motion.motors.is_can_error()
        message.imu_error = False
        message.low_battery = True if self.battery_voltage < self.low_battery_voltage_threadhold else False

        motors: Dict[str, Motor] = self.motion.motors.get_all_motors()
        for index, (motor_tag, motor) in enumerate(motors.items()):
            message.motor_ons[index] = motor.is_enabled()
            message.motor_errors[index] = motor.is_error()
            if motor.angle_limit_breached == True:
                message.physical_limit_error = True
            if motor.over_temperature_protection == True:
                message.over_temperature_error = True
            if motor.under_voltage_protection == True:
                message.under_voltage_error = True
            if motor.is_comms_error() == True:
                message.motor_communication_error = True

        message.battery_voltage = self.battery_voltage
        message.gamepad_battery_percent = self.gamepad.get_battery_life_percent()
        self.aux.send_at_rate(message.pack())
        self.aux.check_for_commands()

    def forward_states(self):
        system_status = SystemStatus()
        system_status.opMode.state = self.op_mode

        system_status.motion.state = self.motion.get_motion_state()
        system_status.target_motion.state = self.motion.get_target_motion_state()
        system_status.gait.state = self.motion.gait
        system_status.ik.status = Status.ERROR if self.motion.get_quad().get_ik_error() else Status.NONE
        system_status.joint_angle.status = Status.ERROR if self.motion.get_quad().get_joint_angle_error() else Status.NONE
        system_status.input.state = self.input_mode
        system_status.loopTimes.main = self.main_loop_completion_time_ms
        system_status.loopTimes.motion = self.motion.get_loop_time_ms()
        system_status.loopTimes.can0 = self.motion.motors.get_can_loop_time("can0")
        system_status.loopTimes.can1 = self.motion.motors.get_can_loop_time("can1")

        system_status.motor.status = self.motion.motors.get_status()
        # system_status.gpio.status = self.hardware.get_gpio_status()
        system_status.smbus.status = self.hardware.get_smbus_status()
        # system_status.power_sensor.status = self.hardware.get_power_sensor_status()
        system_status.imu.status = self.hardware.get_imu_status()
        system_status.imu.roll = self.hardware.get_imu_data().roll
        system_status.imu.pitch = self.hardware.get_imu_data().pitch
        system_status.can0.status = self.motion.motors.get_can_status("can0")
        system_status.can1.status = self.motion.motors.get_can_status("can1")
        system_status.gamepad.status = self.gamepad.get_status()
        system_status.gamepad.battery = self.gamepad.get_battery_life_str()
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

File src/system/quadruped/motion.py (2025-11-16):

from time import time, sleep
from threading import Thread, Lock, Event
from typing import List, Dict, Tuple, Callable
from rich import print  # Overrides print and injects colors

from quadruped.point import Point, get_distance_xy
from quadruped.quad import Quad, LegName
from quadruped.transition_planner import TransitionPlanner
from quadruped.parameters.ik_parameters import IKParameters
from quadruped.parameters.motion_parameters import MotionParameters
from quadruped.gait_planner import Gait
from quadruped.trajectory_planner import TrajectoryPlanner, Trajectory, Trajectories
from quadruped.interfaces import Status, OpMode, MotionState, LegName, JointName, AngleUnits
from hardware.interfaces import ImuData
from motors.motors import Motors
from motors.interfaces import MotorName, MotorSpeeds
from utilities.utilities import scale_value, angle_difference_deg

"""
    Applies gaits and transitions to the quadruped.
    Processes user inputs as speed and directions.
"""


class Motion:
    def __init__(self, op_mode: OpMode):
        self.op_mode = op_mode
        self.tag = "Motion"

        self._get_imu_data: Callable[[], ImuData] = None

        self.trajector_planner: TrajectoryPlanner = TrajectoryPlanner()

        self.motion_state: MotionState = MotionState.STANDBY
        self.target_motion_state: MotionState = MotionState.STANDBY
        self.previous_target_motion_state: MotionState = MotionState.STANDBY
        self.target_gait: Gait = Gait.TROT
        self.trajector_planner.gait = Gait.TROT

        self.quad = Quad()
        self.motion_parameters: MotionParameters = MotionParameters()
        self.ik_parameters: IKParameters = IKParameters()

        self.phase_time: float = 0
        self.phase_time_rate_fast: float = 0.0125

        self.pose_time: float = 0
        self.pose_time_rate: float = 0.005
        self.pose_period: float = 1

        self.transition_time: float = 0
        self.transition_time_rate: float = 0.010

        self.idle_time: float = 0
        self.idle_time_trigger_seconds: float = 30
        self.idle_flag: bool = True

        self.forward_velocity: float = 0
        self.lateral_velocity: float = 0
        self.angular_velocity: float = 0
        self.angular_velocity_target: float = 0
        self.angular_velocity_slew_rate_seconds: float = 2
        self.angular_velocity_time: float = 0

        self.transition_enable: bool = False # Config
        self.transition_planner = TransitionPlanner(touchdown_period=0.15, arc_period=0.3, height=0.025)
        self.transition_start_foot_points: Dict[LegName, Point] = {}
        self.transition_end_foot_points: Dict[LegName, Point] = {}
        self.transition_angular_velocity: float = 0
        self.transition_lateral_velocity: float = 0
        self.transition_forward_velocity: float = 0
        self.transition_angle_threadhold: float = 20

        self.soft_transition_enable: bool = False # Config
        self.soft_transition_flag: bool = False
        self.soft_transition_legs_started_swing: Dict[LegName, bool] = []
        self.soft_transition_previous_foot_points: Dict[LegName, Point] = self.quad.get_foot_points()

        self.transition_hold_flag: bool = False

        self.lock = Lock()
        self.exit_event = Event()

        if self.op_mode is OpMode.DEV:
            self.set_target_motion_state(MotionState.WALK, force=True)
        elif self.op_mode is OpMode.LIVE:
            self.set_target_motion_state(MotionState.STANDBY)

        allow_enable = True if self.op_mode is OpMode.LIVE else False
        self.motors: Motors = Motors(allow_enable)

        self.loop_min_rate_seconds: float = 0.010
        self.loop_completion_time_ms: float = 0.0
        self._start()

    ###############################################################################
    # Thread
    ###############################################################################

    def _start(self):
        print(f"[{self.tag}] starting worker thread")
        self.thread_handle = Thread(target=self._worker)
        self.thread_handle.start()

    def _stop(self):
        print(f"[{self.tag}] stoping worker thread")
        if self.thread_handle and self.thread_handle.is_alive():
            self.exit_event.set()
            self.thread_handle.join()

    def _worker(self):
        self.exit_event.clear()
        print(f"[{self.tag}] worker thread started")
        while not self.exit_event.is_set():
            loop_time = time()

            with self.lock:
                self._check_idle()
                self._get_inputs()
                self._process_dt()
                self._process_motion_state_changes()
                self._process_gait_changes()
                self._process_motion_state()
                self._apply_joints_angles()

            delta = time() - loop_time

            if delta < self.loop_min_rate_seconds:
                sleep(self.loop_min_rate_seconds - delta)

            with self.lock:
                self.loop_completion_time_ms = (time() - loop_time) * 1000

    def _check_idle(self):
        if self.motion_state is MotionState.WALK:
            if abs(self.motion_parameters.forward_velocity) > 0:
                self.idle_flag = False
                self.idle_time = time()

            if abs(self.motion_parameters.forward_velocity) > 0:
                self.idle_flag = False
                self.idle_time = time()

            if time() - self.idle_time > self.idle_time_trigger_seconds:
                if self.idle_flag == False:
                    self.idle_flag = True
                    if self.idle_flag:
                        print(f"[{self.tag}] idle")
                        self.target_motion_state = MotionState.POSE
                        self._create_transition()
        else:
            if self.motion_state is MotionState.TRANSITION:
                self.idle_flag = False
                self.idle_time = time()

    def _get_inputs(self):
        self.angular_velocity, self.angular_velocity_time = self.motion_parameters.slew_heading(
            self.angular_velocity, self.angular_velocity_time, self.angular_velocity_slew_rate_seconds
        )
        # TEMP SKIP SLEW
        self.forward_velocity = self.motion_parameters.forward_velocity
        self.lateral_velocity = self.motion_parameters.lateral_velocity
        self.angular_velocity = self.motion_parameters.angular_velocity

    def _process_dt(self):
        self.pose_time += self.pose_time_rate

        if self.gait is Gait.RUN:
            self.phase_time += self.phase_time_rate_fast
        else:
            heading_reate = scale_value(self.motion_parameters.get_left_magnitude(), 0, 1, 0, self.phase_time_rate_fast)
            angular_rate = scale_value(abs(self.motion_parameters.angular_velocity), 0, 1, 0, self.phase_time_rate_fast)
            self.phase_time += max(heading_reate, angular_rate)

        self.transition_time += self.transition_time_rate
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

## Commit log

2024-09-02 CAN motor controller tests implemented
    [calcs.ods, eagle-test.kicad_pcb, eagle-test.kicad_sch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]
2024-09-02 add CAN test scripts
    [power_distribution.kicad_sch, power_distribution_2.kicad_pcb]
2024-09-05 PCB update
    [aux-board.kicad_pcb, aux-board.kicad_sch, power_distribution.kicad_pcb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]
2024-09-07 PCB update.
    [aux-board.kicad_sch]
2024-09-11 PCB update; project name change
    [aux-board-B_Cu.gbr, aux-board-B_Mask.gbr, aux-board-B_Silkscreen.gbr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]
2024-09-21 sim model update
    [30degree_aframe__1default.stl, abduction.stl, aframe_side__1default.stl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]
2024-09-22 joint angle config updates and model updates
2024-09-24 added kinematics plot repo
2024-09-24 kinematics plot update
2024-09-25 new kinematics flowing to sim
2024-09-25 added custom exceptions to handle joints out of bounds in IK
2024-09-26 added joint angle check and domain check to IK
2024-09-27 sim.py working again after updating quadruped code; fixed imports
    [30degree_aframe__1default.stl, abduction.stl, aframe_side__1default.stl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]
2024-09-27 changed model xml angles to match kinematics angles (zero positions)
2024-09-27 gamepad disconnect logic updated to provide disconnect check to main thread
2024-09-29 aux pcb update
    [auxiliary-pi-hat.kicad_pcb, auxiliary-pi-hat.kicad_sch]
2024-10-06 motor source upload; file reorg
    [30degree_aframe__1default.stl, abduction.stl, aframe_side__1default.stl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]
2024-10-09 motor calibration script update
2024-10-09 zero motor script update
2024-10-10 updated can interface with better error detection
    [motors.py]
2024-10-13 notes update
    [calcs.ods]
2024-10-17 classed live; added control events to JS; fixed motor on/off all bug
    [aux.py, motors.py]
2024-10-18 motor loop now always checks angles and status, reduces timing bugs
    [motors.py]
2024-10-18 get multi angle fix; added limits and limit check to error states
    [motors.py]
2024-10-18 added startup offset to motors to compensate for 0-360 val
2024-10-19 update motor zero utility with offset flags
2024-10-19 plot.py update to handle no gamepad connected
    [auxiliary-pi-hat.kicad_pcb, auxiliary-pi-hat.kicad_sch, calcs.ods]
2024-10-20 power carrier PCB fix
    [calcs.ods, power_carrier.kicad_pcb, power_carrier.kicad_sch]
2024-10-24 source rename to src
    [30degree_aframe__1default.stl, abduction.stl, aframe_side__1default.stl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]
2024-10-25 sim update with new gamepad; body/leg dict fixes
2024-10-25 cad parts cleanup; parts readme added with links to onshape docs
    [30degree_aframe__1default.stl, abduction.stl, aframe_side__1default.stl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]
2024-10-25 doc update and cleanup
    [bom.ods, calcs.ods]
2024-10-25 motor labels added, wireframe gif added
2024-10-26 aux firmware update: added errors to message and other timeout handlers
    [bom.ods, calcs.ods]
2024-10-27 PCB notes update
    [calcs.ods]
2024-10-27 added buzzer and sequences to aux MCU
    [calcs.ods]
2024-10-27 aux board scripts update; includes shutdown command
2024-10-27 pcb readme added, pcb nodes updated
    [auxiliary-board.kicad_pcb, auxiliary-board.kicad_sch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]
2024-10-27 live.py update: fixes, loop sleep controller, etc.
    [aux.py, motors.py]
2024-10-27 added PID setter to motor interface; add default PID to motors
2024-10-28 aux.py fixes, added aux to live.py, misc fixes
    [aux.py, motors.py]
2024-10-28 aux firmware status message fixes
    [main.cpp, main.h]
2024-10-29 moved motors.py from thread base to simple thread implementation to allow thread restarts
2024-10-29 live.py error reporting bug fixes
    [motors.py]
2024-10-29 added more status errors, LCS rearrange, error string protection added
    [main.cpp, main.h]
2024-10-29 start IMU code
2024-11-02 gamepad battery percent fix and update
    [aux.py]
2024-11-02 kinematics bug fix!
2024-11-02 push assets
    [auxiliary-board.kicad_pcb]
2024-11-02 readme.md update
    [3d-prints.ods, calcs.ods, carbon-fiber-tube-insert.stl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]
2024-11-03 minor bug fix with low aux rate
    [aux.py]
2024-11-03 aux rate bug fix, bool reorg minor
    [main.cpp, main.h]
2024-11-03 docs update
    [bom.ods]
2024-11-04 neopixel bug fix
    [bom.ods]
2024-11-04 aux board joy status color bug fix
    [main.cpp]
2024-11-04 doc update
    [bom.ods, calcs.ods, weights.ods]
2025-07-27 gamepad inputs fixed into quad
    [main.py]
2025-07-28 quad/leg flow rework
2025-07-28 ik_params flowing, feet walking
2025-07-30 adding motor state to UI, etc/
2025-07-30 motor live test working
2025-07-31 starting refactor to use angular velocity
2025-07-31 input v f bugfix
    [motion.py]
2025-08-01 moved ik and ja errors into quad
    [interfaces.py, main.py, motion.py]
2025-08-02 add ground penetration check and prevention
    [hardware.py, interfaces.py, main.py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]
2025-08-02 working on setting up live motors, status report bug fix
    [interfaces.py, main.py, motion.py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]
2025-08-03 zero script fixes, doc updates, misc
    [motion.py, motors.py, zero.py]
2025-08-03 .gitignore update
    [assembly-v20.step, power-calcs.ods]
2025-08-04 testing, minor bug fixes
    [interfaces.py, main.py, motion.py]
2025-08-09 motors into motion for faster data handling
2025-08-09 motion parms update with props and cleanups
2025-08-10 lateral working, quadrant corrections applied
    [motion.py]
2025-08-10 imu connect, passing data
2025-08-10 imu data applied to sim quad
2025-08-17 web ui build
    [bom.ods, power-calcs.ods]
2025-11-15 remove command callback replaced with queue
    [interfaces.py, main.py]
2025-11-15 apply sim yaw to live yaw
